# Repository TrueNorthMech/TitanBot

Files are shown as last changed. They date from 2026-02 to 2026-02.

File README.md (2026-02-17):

# TitanBot: 4-Wheeled Holonomic Robot Platform





TitanBot is a professional-grade, open-source robotics platform inspired by the rugged aesthetic of the Humvee. It features a modular "T-Profile" chassis architecture, integrated cable management, and a holonomic drive system for omnidirectional movement.

## 📺 Project Series
Follow the full build from CAD to Code on YouTube:
[TitanBot Project Playlist](https://www.youtube.com/playlist?list=PL657lv-UAYJ7tOfOpE_gaSxdD-4ZY3b3T)

## 📁 Repository Structure
- **/CAD**: Master FreeCAD (.FCStd) files for all structural components.
- **/STLs**: Ready-to-print mesh files for 3D printing.
- **/Firmware**: Arduino sketches for kinematic control and sensor integration.
- **/Docs**: Wiring diagrams, Bill of Materials (BOM), and assembly guides.

## 🛠 Tech Stack
- **Design:** FreeCAD 1.0.2
- **Electronics:** Arduino Nano / Adafruit Motor Shield V1
- **Power:** 2S Li-Po with INA226 Current Monitoring
- **Sensors:** HC-SR04 Ultrasonic Array

## 🚀 Getting Started
1. Clone the repo: `git clone https://github.com/TrueNorthMech/TitanBot.git`
2. Open the master assembly in the `/CAD` folder using FreeCAD 1.0.2+.
3. Refer to the **Build List** in the YouTube descriptions for step-by-step assembly.

## ⚖ License
This project is licensed under the MIT License - see the [LICENSE](LICENSE) file for details.

---
*Maintained by True North Mechatronics*

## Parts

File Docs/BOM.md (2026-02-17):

# TitanBot Bill of Materials (BOM)

This list contains the off-the-shelf components used to build the TitanBot. All 3D printed and laser-cut parts can be found in the `/STLs` and `/CAD` folders of this repository.

## 🔩 Fasteners & Hardware
| Item | Qty | Notes/Source |
| :--- | :--- | :--- |
| 3mm x 8mm PT Screws | 34 | [AliExpress](https://www.aliexpress.com/item/1005003106186747.html) |
| 3mm x 12mm PT Screws | 20 | [AliExpress](https://www.aliexpress.com/item/1005003106186747.html) |
| M3 x 12mm Machine Screws | 4 | [AliExpress](https://www.aliexpress.com/item/32959139856.html) |
| M3 Hex Nuts | 4 | [AliExpress](https://www.aliexpress.com/item/32977174437.html) |
| TT Gearbox Metal Brackets | 4 | [AliExpress](https://www.aliexpress.com/item/1005009042135237.html) |

## ⚙️ Drivetrain & Motion
| Item | Qty | Notes/Source |
| :--- | :--- | :--- |
| TT Gearbox (1:48 Ratio) | 4 | [AliExpress](https://www.aliexpress.com/item/1005007626575887.html) |
| 60mm Mecanum Wheels | 1 Set | [AliExpress](https://www.aliexpress.com/item/1005005651980933.html) |
| Coded Encoder Disks | 4 | [AliExpress](https://www.aliexpress.com/item/1005005925860851.html) |
| IR Slotted Speed Sensors | 4 | [AliExpress](https://www.aliexpress.com/item/4000301976485.html) |

## 🧠 Control & Logic
| Item | Qty | Notes/Source |
| :--- | :--- | :--- |
| Arduino Uno R3 (Clone) | 1 | [AliExpress](https://www.aliexpress.com/item/1005008488933639.html) |
| Adafruit Motor Shield V1 (Clone) | 1 | [AliExpress](https://www.aliexpress.com/item/2022057125.html) |
| Arduino Nano V3 (Clone) | 2 | [AliExpress](https://www.aliexpress.com/item/1005005367785146.html) |
| Nano V3 Terminal Adapter | 2 | [AliExpress](https://www.aliexpress.com/item/1005010161492858.html) |
| NRF24L01+PA+LNA + Adapter | 2 | [AliExpress](https://www.aliexpress.com/item/1005009624500951.html) |
| PS2 Dual-axis Joystick | 2 | For Remote Control [Link](https://www.aliexpress.com/item/1005008701549090.html) |

## 📡 Sensors & Modules
| Item | Qty | Notes/Source |
| :--- | :--- | :--- |
| HC-SR04 Ultrasonic Sensor | 1+ | [AliExpress](https://www.aliexpress.com/item/1005009006822606.html) |
| INA226 Current/Power Monitor | 1 | [AliExpress](https://www.aliexpress.com/item/1005006151783115.html) |
| GY-271 Magnetometer | 1 | [AliExpress](https://www.aliexpress.com/item/1005009671100691.html) |
| GY-6500 (MPU6500) IMU | 1 | [AliExpress](https://www.aliexpress.com/item/1005007292626670.html) |
| HM-10 Bluetooth Module | 1 | [AliExpress](https://www.aliexpress.com/item/1005005127284690.html) |
| 2S Battery Capacity Indicator | 1 | Blue LED [Link](https://www.aliexpress.com/item/1005009941986414.html) |

## ⚡ Power System
| Item | Qty | Notes/Source |
| :--- | :--- | :--- |
| EVE 25P 18650 Batteries | 2 | 2500mAh [Link](https://www.aliexpress.com/item/1005006161080250.html) |
| HX-2S-JH20 BMS | 1 | 2S Li-ion Protection [Link](https://www.aliexpress.com/item/1005006150203018.html) |
| LM2596S Buck Converter | 1 | Adjustable [Link](https://www.aliexpress.com/item/1005007508685885.html) |
| 2S Type-C LiPo Charger | 1 | Step-up Boost [Link](https://www.aliexpress.com/item/1005004788334469.html) |
| ATC Blade Fuse Box + 10A Fuse | 1 | [Link](https://www.aliexpress.com/item/1005005880777204.html) |
| XT60H Connectors | 1 Pair | [Link](https://www.aliexpress.com/item/1005007099881239.html) |
| KCD11 Rocker Switch | 1 | 10x15mm [Link](https://www.aliexpress.com/item/1005008871215158.html) |

## 🛠️ Tools & Consumables
- **Spot Welder:** SWM-10 Portable [Link](https://www.aliexpress.com/item/1005006032024395.html)
- **Crimpers:** HSC8-4 (Ferrules) and IWISS (Dupont)
- **Wiring:** 18AWG Silicone (Power), 22AWG (Signal)
- **Misc:** Barley Paper, Nickel Strip, Heat Shrink, Non-conductive CPU Paste.

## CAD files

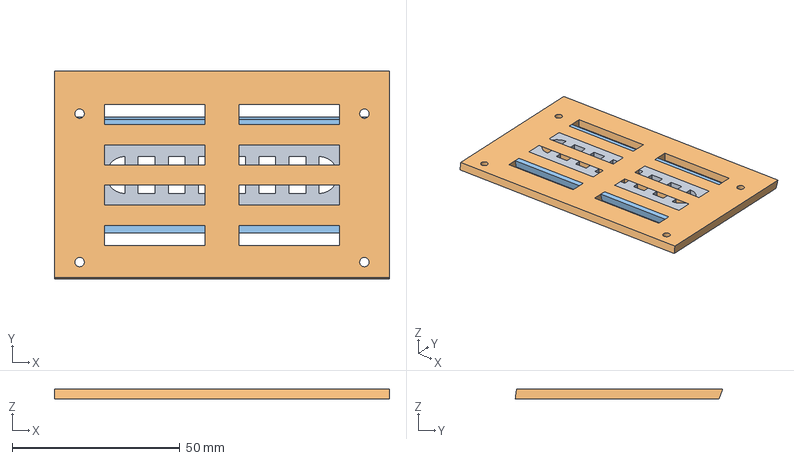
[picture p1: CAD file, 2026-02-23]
CAD/3D_Models/Ep 13 - TitanBot - Forward Cowling Assembly.FCStd
100.0 x 62.0 x 3.00 mm
Grille
Hood
Windshield

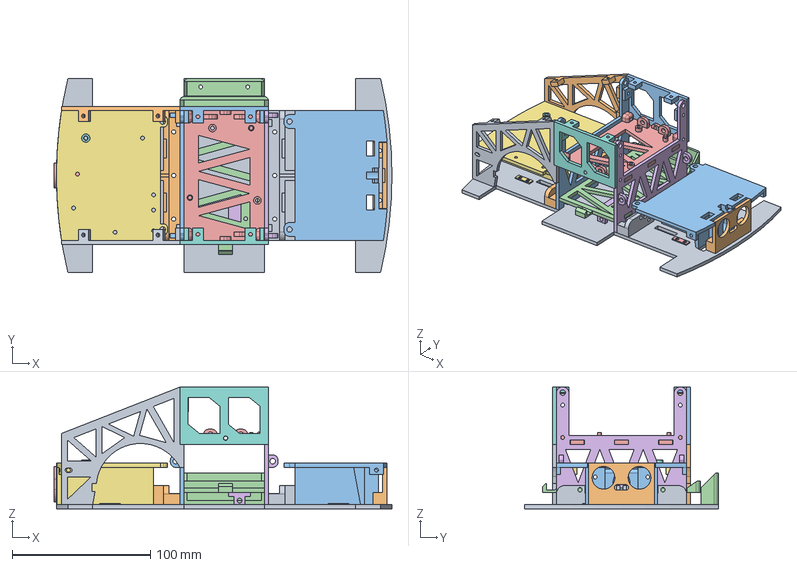
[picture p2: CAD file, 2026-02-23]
CAD/3D_Models/Master Assembly - V2.4 Prototype.FCStd
244.2 x 140.0 x 88.0 mm
Mobility Platform
Rail Pedestal (Rear)
Vertical Frame Rail (Rear)
Battery Tray
Logic Tray
Vertical Frame Rail (Front)
Vetronics Deck
PCB Clearance Spacer
Rail Pedestal (Front)
Ultrasonic Sensor Bezel
Accessory Deck
XT60 Retention Cradle
Switch Adapter Housing
Current Sense Cradle
Gearbox Bracket Shim
Cab Door
Rear Fender Panel - Right
Rear Fender Panel - Left
Cab Door L
Motor Pad001
Gearbox Bracket Shim001

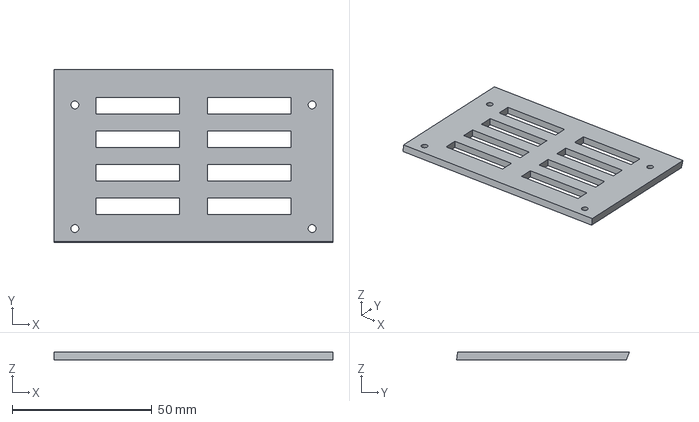
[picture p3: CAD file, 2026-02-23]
CAD/3D_Models/STEP/Ep 13 - TitanBot - Forward Cowling Assembly-Hood.step
100.0 x 62.0 x 3.00 mm

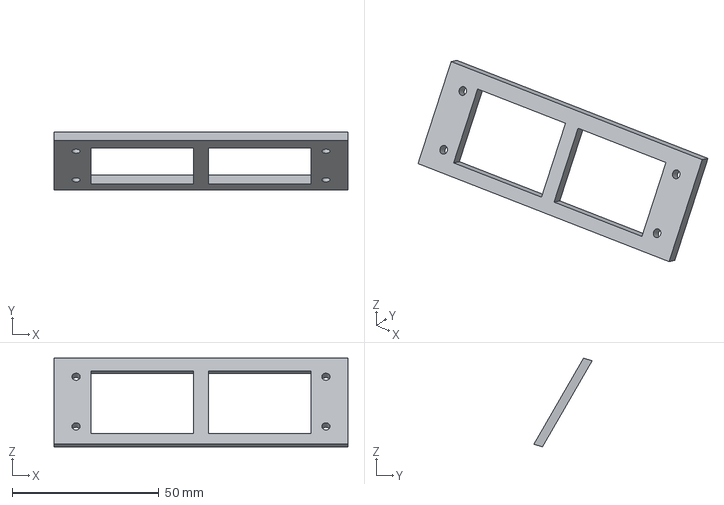
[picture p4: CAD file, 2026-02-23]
CAD/3D_Models/STEP/Ep 13 - TitanBot - Forward Cowling Assembly-Windshield.step
100.0 x 19.8 x 30.2 mm

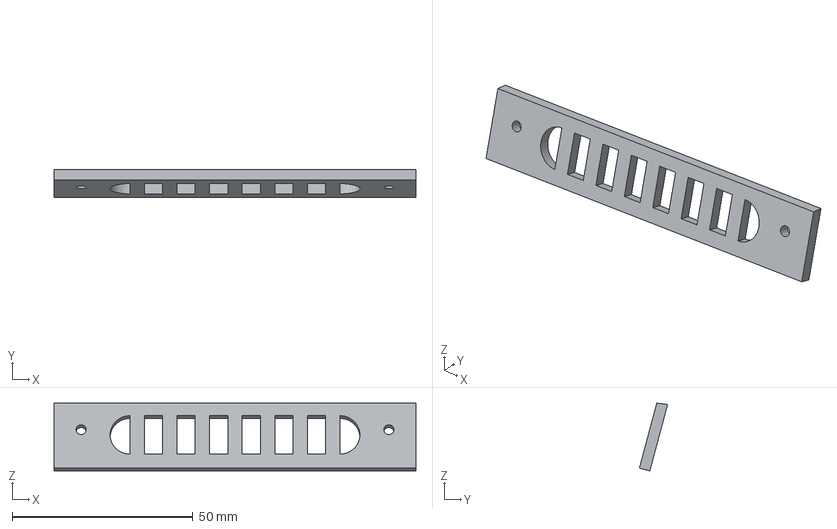
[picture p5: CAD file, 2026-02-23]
CAD/3D_Models/STEP/Ep 13 - TitanBot - Forward Cowling Assembly-Grille.step
100.0 x 7.82 x 18.7 mm

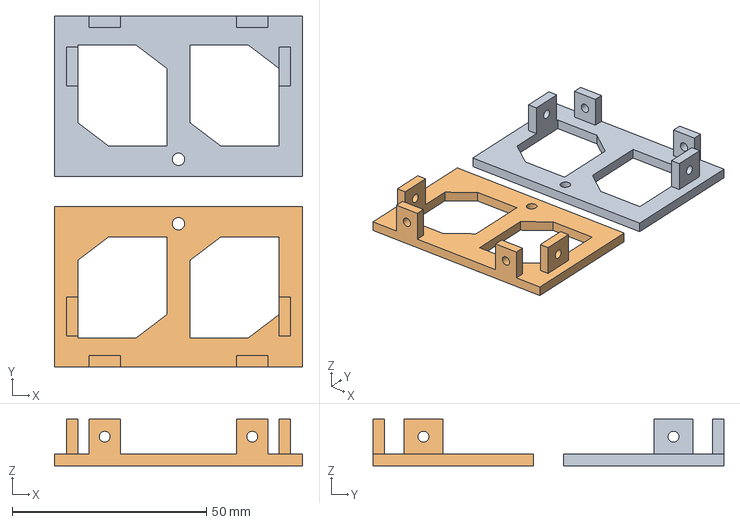
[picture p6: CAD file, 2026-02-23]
CAD/3D_Models/Ep 11 - TitanBot - Citadel Door Panels - v2.5.FCStd
64.0 x 90.4 x 12.0 mm
Left
Right

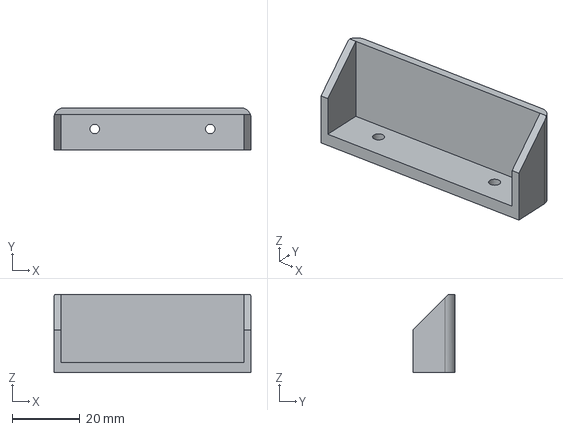
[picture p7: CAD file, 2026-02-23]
CAD/3D_Models/STEP/Ep 8 - TitanBot - Integration Hardware - v2.5-XT60 Retention Cradle.step
58.0 x 12.5 x 23.0 mm

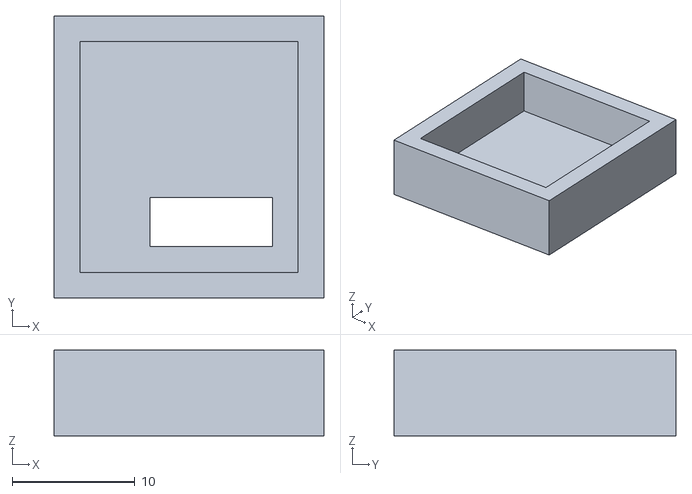
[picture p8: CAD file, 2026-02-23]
STLs/Ep 14 - TitanBot - Citadel Roof Deck-GY-271 Restraint Cap.stl
22.0 x 23.0 x 7.00

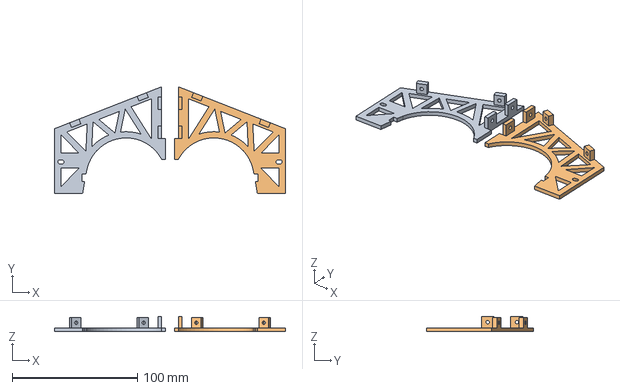
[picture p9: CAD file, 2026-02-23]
CAD/3D_Models/Ep 10 - TitanBot - Rear Fender Panel - v2.5.FCStd
184.3 x 85.0 x 12.0 mm
Left
Right

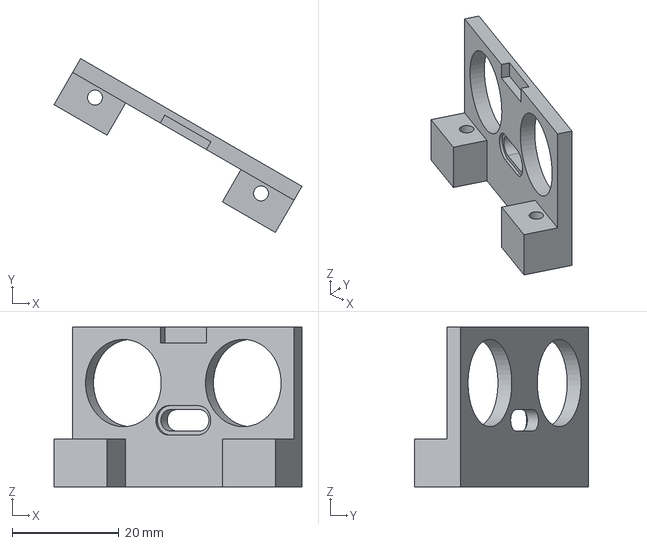
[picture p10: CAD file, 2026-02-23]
CAD/3D_Models/STEP/Ep 9 - TitanBot - Sensor Mounts - v2.5-Ultrasonic Sensor Bezel.step
46.6 x 32.7 x 30.0 mm

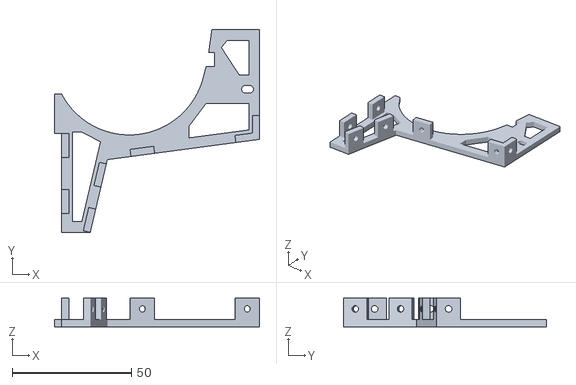
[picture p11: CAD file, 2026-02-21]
STLs/Ep 12 - TitanBot - Front Fender Panel - Right.stl
85.9 x 85.0 x 12.0

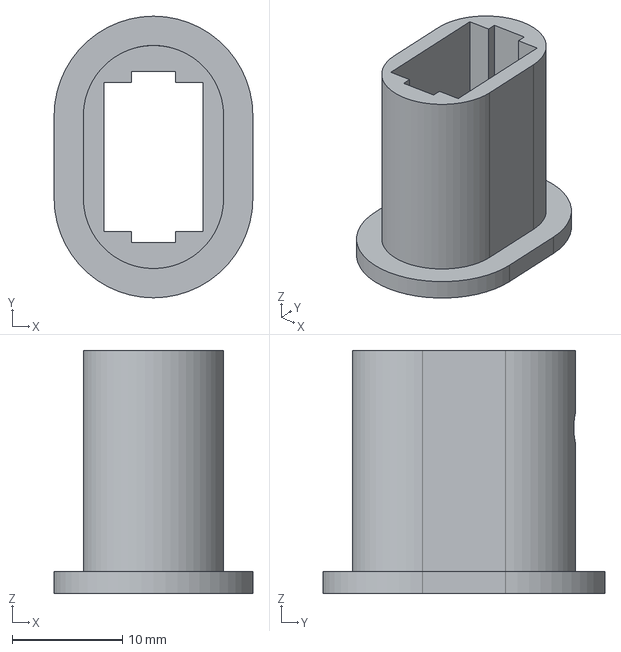
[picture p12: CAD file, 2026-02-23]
CAD/3D_Models/STEP/Ep 8 - TitanBot - Integration Hardware - v2.5-Switch Adapter Housing.step
18.0 x 25.5 x 22.0 mm

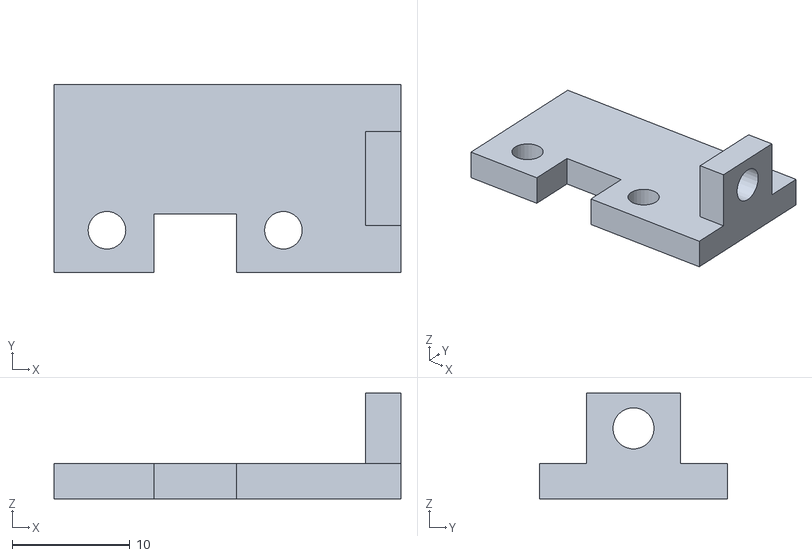
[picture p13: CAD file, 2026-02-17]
STLs/Ep 9 - TitanBot - Current Sense Cradle.stl
29.5 x 16.0 x 9.00

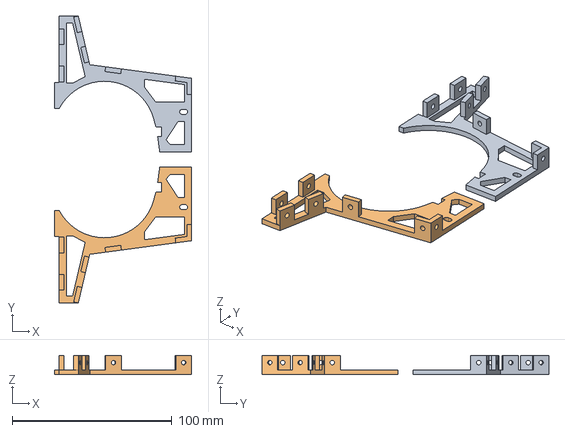
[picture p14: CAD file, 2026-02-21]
CAD/3D_Models/Ep 12 - TitanBot - Front Fender Panels.FCStd
85.9 x 179.7 x 12.0 mm
Left
Right

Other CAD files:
STLs/Ep 12 - TitanBot - Front Fender Panel - Left.stl
CAD/3D_Models/STEP/Ep 12 - TitanBot - Front Fender Panels-Right.step
CAD/3D_Models/STEP/Ep 10 - TitanBot - Rear Fender Panel - v2.5-Left.step
STLs/Ep 11 - TitanBot - Citadel Door Panels - Left.stl
CAD/3D_Models/Ep 1 - TitanBot - Mobility Base - v2.5.FCStd
CAD/3D_Models/Ep 14 - TitanBot - Citadel Roof Deck.FCStd
CAD/3D_Models/Ep 2 - TitanBot - Rail Pedestal - v2.5.FCStd
CAD/3D_Models/Ep 3 - TitanBot - Vertical Frame Rail - v2.5.FCStd
CAD/3D_Models/Ep 4 - TitanBot - Battery Tray - v2.5.FCStd
CAD/3D_Models/Ep 5 - TitanBot - Kinematic Control Tray - v2.5.FCStd
CAD/3D_Models/Ep 6 - TitanBot - Vetronics Deck - v2.5.FCStd
CAD/3D_Models/Ep 7 - TitanBot - Accessory Deck - v2.5.FCStd
CAD/3D_Models/Ep 8 - TitanBot - Integration Hardware - v2.5.FCStd
CAD/3D_Models/Ep 9 - TitanBot - Sensor Mounts - v2.5.FCStd
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

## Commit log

2026-02-17 Add comprehensive Bill of Materials (BOM) with AliExpress links
2026-02-17 Added FreeCAD files for parts 1 - 11
    [Ep 1 - TitanBot - Mobility Base - v2.5.FCStd, Ep 10 - TitanBot - Rear Fender Panel - v2.5.FCStd, Ep 11 - TitanBot - Citadel Door Panels - v2.5.FCStd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]
2026-02-17 Added STL files for parts 1 - 11
    [Ep 1 - TitanBot - Mobility Base.stl, Ep 10 - TitanBot - Rear Fender Panel - Left.stl, Ep 10 - TitanBot - Rear Fender Panel - Right.stl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]
2026-02-21 Added FreeCAD project file and STL files for Episode 12
    [Ep 12 - TitanBot - Front Fender Panel - Left.stl, Ep 12 - TitanBot - Front Fender Panel - Right.stl, Ep 12 - TitanBot - Front Fender Panels.FCStd]
2026-02-23 Added FreeCAD project file and STL files for Episodes 13 & 14. Also added STEP files for all parts
    [Ep 1 - TitanBot - Mobility Base - v2.5.step, Ep 10 - TitanBot - Rear Fender Panel - v2.5-Left.step, Ep 10 - TitanBot - Rear Fender Panel - v2.5-Right.step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]

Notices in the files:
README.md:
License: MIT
